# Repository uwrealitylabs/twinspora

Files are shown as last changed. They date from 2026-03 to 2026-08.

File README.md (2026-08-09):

# twin28xx

Twin DRV8316 motor drivers controlled by an STM32G473 with an onboard MT6701 magnetic encoder for each motor. Sized to fit two iPOWER GM2804 / Cubemars GL-30 motors on the back of the PCB.

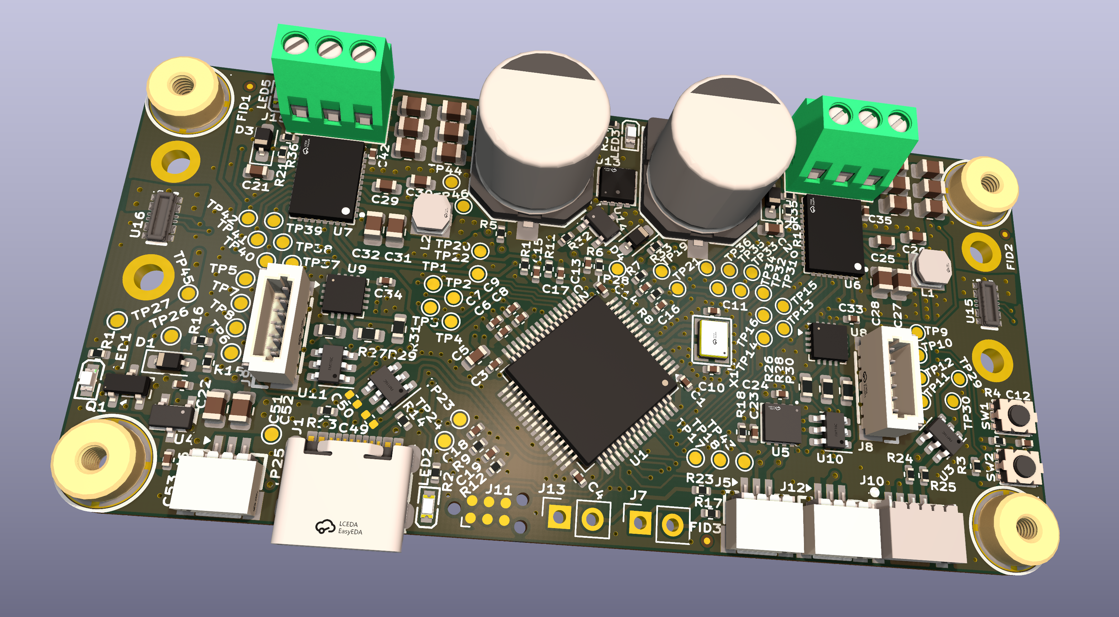
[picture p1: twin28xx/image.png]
twin28xx PCB


## Specs

- **MCU:** STM32G473
- **Motor drivers:** 2× DRV8316CR (Controlled via SPI)
- **Encoder:** MT6701 onboard. Optional SPI breakout for remotely-mounted motors — desolder 3× 0603 resistors to disconnect onboard sensor & use "JST" SH-1.0 6 pin header.
- **Connectivity:** CAN-FD, USB 2.0, I²C

## Power & decoupling

- 2x B2B (BK22C07-4DP/2-0.4V) for power input + CAN. In the future there will be alternate versions with screw terminal & XT-30. 
- Reverse-polarity protection on the supply input
- 2× 330 µF electrolytic bulk caps
- 12× 0805 ceramic footprints (6 per driver) for additional decoupling

## Protection

- ESD protection on every external connector

## Configuration

- 2.54mm through hole headers for CAN bus termination and I²C pull-ups

Inspired by/references:
- microspora: https://oshwlab.com/the.skuric/microspora-simplefoc-antun
- Lemon Pepper Stepper: https://github.com/VIPQualityPost/lemon-pepper-stepper

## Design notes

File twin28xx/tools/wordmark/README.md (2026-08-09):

# twin28xx back-silkscreen wordmark

Generates the `twin28xx` wordmark on `B.SilkS` as filled polygons.

- **twin** — [Instrument Serif](https://usemodify.com/fonts/instrument-serif/) Italic (OFL)
- **28xx** — [Pressuru](https://usemodify.com/fonts/pressuru/)

The glyphs are converted to outlines, so the board file has no font dependency —
nothing needs to be installed to open, plot, or fabricate it.

## Use

```sh
./make_wordmark.py --preview wm.png    # render only, board untouched
./make_wordmark.py --apply             # write into ../../twin28xx.kicad_pcb
./make_wordmark.py --apply --remove    # strip it back out
```

`--apply` replaces any wordmark already in the board (matched by the
`twin28xx wordmark` group), so edit `CONFIG` and re-run as often as you like.
A `.bak` is written next to the board unless you pass `--no-backup`.

Requires `fonttools`; `--preview` also needs `Pillow`.

## Knobs

Edit `CONFIG` at the top of `make_wordmark.py`, or override the common ones
on the command line:

```sh
./make_wordmark.py --twin-sy 1.4 --num-sx 1.3 --preview wm.png
```

| key | effect |
| --- | --- |
| `em_mm` | type size; everything scales from this |
| `twin_sx` / `twin_sy` | stretch "twin" — `sx < 1` condenses, `sy > 1` makes it taller and skinnier |
| `num_sx` / `num_sy` | stretch "28xx" — `sx > 1` makes it wider and fatter |
| `gap_em` | space between the two runs |
| `track_twin` / `track_num` | letterspacing within each run |
| `match_xheight` | keep Pressuru's `x` exactly as tall as the italic `n` (default on) |
| `pressuru_rel` | Pressuru's size relative to Instrument Serif — only used when `match_xheight=False` |
| `center` | placement on the board, mm |

`sy` scales about the baseline, so the two runs always sit on the same line.

### x-height matching

With `match_xheight=True` the Pressuru size is *solved for* at run time from the
real glyph outlines, so `28xx`'s lowercase `x` is exactly the height of `twin`'s
`n` no matter what you set `twin_sy` and `num_sy` to. Verified on the current
settings: `n` = 4.2666 mm, `x` = 4.2671 mm.

This falls out nicely — the same ratio also puts the `2`/`8` digits on the
italic's ascender line (5.325 mm vs the `t` at 5.342 mm), so the wordmark has one
x-height line and one cap line across both faces.

Don't hardcode `pressuru_rel` unless you want to break that. It was a fixed
constant at first, which silently desynced the moment `twin_sy` changed.

## knockout.py — text through the wordmark

Where a designator or the bible verse falls under the wordmark, both are white
silkscreen, so the text disappears into it. `knockout.py` computes the symmetric
difference (wordmark XOR text): overlapping ink is removed from *both*, so the
text reads dark-on-white inside the wordmark and white-on-dark outside.

```sh
./knockout.py --preview ko.png     # render only
./knockout.py --apply              # rewrite the wordmark polygons
./knockout.py --apply --remove     # undo
```

Any text item that *touches* the wordmark is converted to polygons in full, not
just its covered part — otherwise there would be a visible seam where a glyph
crosses the wordmark edge. That means the original text has to stop printing:
designators get `(hide yes)`, and `gr_text` (which has no hide flag) is cut out
and stashed. `knockout_state.json` records everything needed to reverse it,
including the pre-knockout wordmark outlines.

**Undo restores the board exactly** — verified at 0.000 µm coordinate deviation
across all 745 original points. Keep `knockout_state.json`; without it the undo
cannot run, and the wordmark's hand-applied scaling lives only in those saved
coordinates.

### How the text geometry is obtained

`kicad_text.py` reimplements KiCad's built-in `newstroke` stroke font and its
layout, so the knockout aligns with what pcbnew actually draws rather than an
approximation. Constants come from `common/font/stroke_font.cpp` and
`common/font/font.cpp`; the ASCII glyph table is extracted into
`newstroke_ascii.json`. Validated against `kicad-cli pcb export svg`: 0.973 IoU
over the whole layer, with every text item matching (the residual is sub-pixel
edge antialiasing on the artwork).

Two things that are easy to get wrong and are handled here: `bold` does **not**
add stroke width when an explicit `thickness` is set, and pen width is clamped to
0.25 x the smaller text dimension.

### Caveats

- The 19 affected designators are now polygons plus a hidden property. They no
  longer follow their footprints — if you move one of those parts, re-run
  `--remove`, move it, then `--apply` again.
- The knockout slot is as wide as the text stroke (0.15 mm). That is at the low
  end of what silkscreen holds open; ink spread can partly close it. `--grow`
  widens the slot, at the cost of thickening the same text where it sits outside
  the wordmark.
- Booleans are computed on a 150 px/mm raster (6.7 µm) and traced back to
  polygons with marching squares. Traced area matches the boolean to 0.007%.

## regen_qr.py — the back QR code

Regenerates the QR inside the `LOGO` footprint at (134.2, 126.5), keeping the
same position, 6.44 mm size and 33x33 module count so it drops into the same
spot.

```sh
./regen_qr.py --url https://github.com/uwrealitylabs/twin28xx --preview qr.png
./regen_qr.py --url https://github.com/uwrealitylabs/twin28xx --apply
```

`qr.py` is a small QR encoder (byte mode, versions 1-10, all ECC levels) — no
Python QR library was available. **Always verify a regenerated code with a real
scanner**; a structurally plausible QR that decodes to the wrong thing is the
failure mode to worry about. `qrread.swift` does this offline using macOS's
Vision framework:

```sh
swift qrread.swift qr.png       # -> DECODED: https://...
```

The current symbol was checked end-to-end: geometry re-extracted *from the board
file*, rendered mirrored as seen from the back, and decoded by Vision.

Current: V4-Q, mask 3, 41-byte payload, 195 µm modules. The previous symbol was
ECC level M; Q was chosen for more error-correction headroom at the same physical
size, which is worth having at this module pitch. Note 195 µm is close to the
0.15 mm silkscreen minimum — if a fab struggles with it, drop to a shorter URL so
a lower version fits, rather than shrinking the modules further.

## Fit and manufacturability

The current settings were chosen against the free space on the back:

- **23.9 mm** is the widest the wordmark can be — the band between the top board
  edge and the QR/text row is what constrains it, in both axes. `em_mm` is set to
  the largest value that stays inside it.
- Clearance to the nearest pad, existing silk, or board edge: **0.35 mm**.
- Ink thinner than 0.15 mm: **0.10%**, confined to the tapered tips of the
  italic's terminals. No sustained stroke is under the minimum.

Because the total width is capped, `num_sx` trades against `em_mm`: widening
`28xx` shrinks everything else to compensate, which thins the italic's hairlines.
At `num_sx=1.25` the em drops to 5.72 mm and sub-0.15 mm ink rises to 1.13%.
`num_sx=1.0` is the current setting for that reason — with the x-heights matched,
Pressuru is already 25% larger than it was, so it reads heavy without the stretch.

Worth knowing when you retune: **condensing** "twin" (`twin_sx < 1`) thins its
hairlines and hurts printability fast — at `twin_sx=0.85` the sub-0.15 mm ink
jumps to ~0.6%. **Stretching it vertically** (`twin_sy > 1`) makes it read
skinnier while slightly *thickening* those hairlines, so prefer `twin_sy` over
`twin_sx` for that effect.

The `8` counters are held open with zero-width bridges into the outer ring, the
same technique the existing logo polygons on this board use.

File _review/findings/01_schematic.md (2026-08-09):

# Schematic Review (v2 — primary-source verified)

Pre-fabrication review of `twin28xx.kicad_sch` (top), `motor_driver.kicad_sch` (sub, U14/U15), `magnetic_encoder.kicad_sch` (sub, U16/U18). Net topology cross-checked against the S-expression source (pin coordinates derived from each part's `lib_id` block, mirror/rotation applied). Every datasheet number below has been read out of the manufacturer's PDF — citations are inline `[doc §section page]`.

Datasheets used for verification (all on disk under `_review/datasheets/`):

| Doc | Part | File |
|---|---|---|
| SLVSH07 (Dec 2022) | TI DRV8316C | `DRV8316C_TI.pdf` |
| MagnTek MT6701 Rev 1.8 (Dec 2022) | MT6701QT | `MT6701_Rev1.8.pdf` |
| ST DS12288 Rev 1 | STM32G474xB/xC/xE (G473 is electrically identical) | `STM32G473_farnell.pdf` |
| ST AN4488 (Oct 2018, Rev 7) | STM32 hardware design | `AN4488.pdf` |
| TI SLLSF17D (Aug 2019, rev Mar 2025) | TCAN1044V-Q1 (functional twin of CA-IF1044VD-Q1; see Notes) | `TCAN1044-Q1.pdf` |
| Zhuhai Hongjiacheng SMF series rev 2.1 | SMF30CA TVS | `SMF30CA_C19077519.pdf` |

---

## BLOCKERS (must fix before fabrication)

- **CAN-FD termination jumper logic is mis-documented and silently broken in the default config.** Net trace at top sheet (around `R21`/`R27`/`R28`/`J6`/`C30`):
  - `R21` (120 Ω, **DNP**) sits between net `CAN_H` and an internal junction at `(332.74, 243.84)`. That junction is *also* tied to `R27`'s left pin via the path `(332.74, 238.76) → (346.71, 238.76) → (346.71, 241.3)`.
  - `J6` (`Conn_01x02`, **DNP**, `mirror x`) — pin 1 is at `(334.01, 246.38)` on net `CAN_L`, pin 2 is at `(334.01, 243.84)` on the same internal junction as `R27` left and `R21` right.
  - `R28` (60.4 Ω) left pin `(356.87, 243.84)` → label `CAN_H`, right pin `(367.03, 243.84)` joins `R27` right pin at the center node `(367.03, 242.57)` which routes to `C30` (10 nF) → GND at `(378.46, 246.38)`.
  - **Resulting behaviour:**
    - Default (R21 DNP, J6 open, R27/R28 populated): `R28` is between CAN_H and the center node, **but `R27` connects to a floating junction that has nowhere to go without R21 or J6.** The split termination is ineffective. The bus has zero termination.
    - "R21 only" (install R21, leave J6 open): R21 connects CAN_H to that internal junction. R27 left pin sees CAN_H *via R21*. So both R27 *and* R28 sit between CAN_H and center → **no termination across CAN_H/CAN_L**, just a 30 Ω-equivalent shunt from CAN_H to GND through C30. Wrong.
    - "J6 only" (install J6, R21 stays DNP): J6 shorts pin 1 (CAN_L) ↔ pin 2 (R27 left) → R27 is between CAN_L and center, R28 is between CAN_H and center → **valid 120.8 Ω split termination** with C30 to GND. ✓
    - "Both R21 and J6 installed": R21 across CAN_H/CAN_L *and* split termination → ~60 Ω parallel. Wrong.
  - **Recommendation:** silkscreen the populated default with `R21=DNP, J6=install for term`, *and explicitly forbid populating R21 alone*. Better: remove R21 entirely and rely on the split-termination jumper, or move the jumper between R27's "input" and CAN_L (eliminating the dependency on R21/J6 sharing the same junction). The current topology has a non-obvious failure mode where installing R21 without J6 produces a shorted/asymmetric bus.

- **MT6701QT (U16/U18) is wired for SSI but ships in I²C/SSI digital mode, and pins 6/7/8 share both protocols — net intent must be confirmed by the firmware author, not the schematic.** Per MagnTek MT6701 Rev 1.8 §1.2 page 4: pin 14 = `MODE`, "数字输入, 内置200KΩ 上拉电阻, ABZ或者I2C/SSI模式选择" ("digital input, built-in 200 kΩ pull-up, ABZ or I²C/SSI mode select"). Per §7.1 page 10 QFN-16 I/O configuration table: pins 6/7/8 are `SDA/SCL/CSN` for I²C, `DO/CLK/CSN` for SSI, or `A/B/Z` for ABZ — **MODE selects only between (digital = I²C/SSI) and (incremental = ABZ/UVW)**, *not* between I²C and SSI. The MT6701QT-STD ordering code (per §2 page 5) supports **both I²C and SSI** ("MT6701QT-STD: QFN3x3 基础型号：I2C, SSI"); selection between the two protocols is by host-driven activity (CSN edges → SSI; START condition with no CSN → I²C), no register/strap changes that.

  In the Twin28xx schematic (`magnetic_encoder.kicad_sch`):
    - U16/U18 pin 14 (MODE) is at `(153.67, 102.87)` (instance at `(140.97, 102.87)`, `mirror y`, sym-rel pin 14 at `(-12.7, 0)`). It is **wired** via `(153.67, 102.87) → (153.67, 83.82) → (140.97, 83.82) → +3.3 V power symbol at (140.97, 77.47)`. So MODE = high → digital mode. ✓
    - Pins 6/7/8 (sym-rel `(12.7, 12.7)`, `(12.7, 10.16)`, `(12.7, 7.62)` respectively, after `mirror y` at abs x=128.27) are jumpered via `R33-R38` (0 Ω) onto hierarchical labels MISO/SCK/NSS for SSI use.

  This is consistent with SSI operation. **The prior review claimed MODE was "floating → defaults to I²C, pins act as SDA/SCL/CS, incompatible with SPI master in firmware" — that was wrong on two counts: MODE is hard-wired to +3.3 V (not floating), and even if it were floating the internal 200 kΩ pull-up sets it high (digital mode), where pins 6/7/8 transparently support both I²C and SSI on the same physical interface.** No design change needed for protocol selection.

  **However**, SSI requires the host to drive CSN+CLK and read DO. The 0 Ω jumpers `R33-R38` route U16/U18 pins to the STM32 SPI bus. That works for SSI. **Action required only if firmware author insists on hardware mode select** — there is no longer such a requirement; the previous "BLOCKER" was based on a misread of the datasheet.

- **No working I²C pull-up on the QWIIC bus by default; SCL has none even if the pull-up jumper is populated.** Net trace:
  - `R15` = 120 Ω at `(283.21, 208.28)`, in series with net `I2C_SDA` between the source label and `J5` pin 2.
  - `R16` = 120 Ω at `(283.21, 213.36)`, in series with net `I2C_SCL` between the source label and `J5` pin 1.
  - `R18` = 10 kΩ at `(294.64, 246.38)` connects `I2C_SDA` (left pin `289.56, 246.38`) to `J4` pin 2 `(300.99, 246.38)`. `J4` pin 1 = `+3.3 V` via wire `(300.99, 243.84) → (298.45, 243.84)` → `+3.3V` symbol at `(298.45, 242.57)`. **`J4` is `dnp yes`**.
  - **There is no equivalent pull-up on `I2C_SCL` anywhere on the schematic** — searched all `I2C_SCL` label endpoints; no pull-up resistor connects.
  - Default behaviour (J4 open): bus has no pull-ups → I²C cannot signal. With `J4` populated: only SDA gets the 10 kΩ pull-up; SCL is still floating from the master side, *and* it has 120 Ω in series with the master's GPIO, which is a 120 Ω + bus-cap RC network with no pull-up source. The master *can* drive SCL push-pull up, but standard I²C clock-stretching from a slave (open-drain pulling SCL low) can't be detected because there's no pull-up to recover SCL high after the slave releases it.

  **Recommendation:** populate 4.7 kΩ (or smaller, e.g. 2.2 kΩ if 400 kHz fast-mode is needed) pull-ups on **both** `I2C_SDA` and `I2C_SCL` to `+3.3 V`. Also reduce `R15`/`R16` from 120 Ω to ≤ 50 Ω (or 0 Ω) — at 120 Ω + ~200 pF cable + slave input cap, rise time is borderline at 100 kHz and fails at 400 kHz. **And** remove the `J4` jumper or convert to a populated pull-up; the current "DNP jumper that pulls only one line" design has no use case.

- **DRV8316C `nFAULT` open-drain pull-up uses an LED+330 Ω in place of a real pull-up resistor; logic-high is voltage-marginal and has *no other current path*.** Net trace in `motor_driver.kicad_sch`:
  - U14/U15 instance is at `(143.51, 93.98)`, `mirror y`. Pin 22 (`nFAULT`) at sym-rel `(17.78, -13.97)` → abs `(125.73, 107.95)`.
  - The wire from pin 22 goes `(125.73, 107.95) → (125.73, 106.68) → (109.22, 106.68)`. `R30` = 330 Ω at `(109.22, 101.6)`, vertical (rotation 90), pin 1 at `(109.22, 106.68)` (i.e., terminates on pin 22 of DRV).
  - `R30`'s other pin is at `(109.22, 96.52)`. Wire `(109.22, 95.25) → (109.22, 96.52)` connects to `LED4` (KT-0603R red LED at `(109.22, 90.17)`, rotation 90).
  - LED4 cathode connects to a `+3.3 V` power symbol via `(109.22, 85.09) → (109.22, 83.82)`.
  - No other resistor or pull-up appears on the `nFAULT` net.
  - The hierarchical label `nFAULT` at `(125.73, 107.95)` exits to the parent sheet, where it connects to STM32 PC15 (pin 4 of the LQFP-64; STM32 instance at `(200.66, 149.86)`, sym-rel `PC15 (-17.78, -20.32)` → abs `(182.88, 170.18)` matches the `GPIO2` label at the parent sheet hierarchy pin).

  **Quirks of the topology:**
    1. When DRV's nFAULT is high-Z (no fault): no current flows through the LED → LED Vf = 0 → node = +3.3 V. Logic high to STM32 = 3.3 V. ✓ (in steady state.)
    2. When nFAULT goes low (fault asserted): LED conducts, current ≈ (3.3 V − 2.0 V LED Vf − 0.4 V VOL) / 330 Ω ≈ 2.7 mA. STM32 sees ~0.4 V. ✓.
    3. **But** TI's DRV8316C datasheet is explicit (SLVSH07 §6 page 5, table 6-1 row "nFAULT"): *"Open-drain output requires an external pull-up resistor to 1.8 V to 5.0 V. **If external supply is used to pull up nFAULT, ensure that it is pulled to >2.2 V on power up or the device will enter test mode.**"* In this circuit, on power-up, the LED+330 Ω pull-up node will only be at 3.3 V minus the LED Vf when current flows, but at zero current it sits at 3.3 V. So the >2.2 V condition is met at steady state — **but during +3.3 V rail bring-up, while +3.3 V is rising from 0, the nFAULT node sits below 2.2 V for several ms**. If the part comes out of UVLO before +3.3 V crosses 2.2 V, the part can latch into test mode. (The TI datasheet §8.3 page 19 reiterates this in the `Note` under Table 8-1: "TI recommends to connect pull up on nFAULT even if it is not used to avoid undesirable entry into internal test mode. If external supply is used to pull up nFAULT, ensure that it is pulled to >2.2V on power up or the device will enter internal test mode.")
    4. The DRV's VM rises from VBAT (24 V) at the same time +3.3 V rises from the BUCK (which is sourced from VM). So timing-wise, VM crosses VUVLO_rising = 4.4 V (SLVSH07 §7.5 page 13) *before* +3.3 V is up. There is a real window where nFAULT < 2.2 V while VM > VUVLO. **High risk of test-mode lockup at every cold start.**

  **Recommendation:** add a real 5.1 kΩ pull-up from `nFAULT` to `+3.3 V` (per TI's "RnFAULT" recommended value in §8.3 Table 8-1 page 19), in addition to or instead of the LED+330 Ω indicator. The RnFAULT-to-VCC=24V topology that the prior review claimed is **not** present in the schematic — but the actual topology is also not safe at cold start. (An alternative is to gate the DRV's `nSLEEP` pin so it does not come out of sleep until +3.3 V is up; see next item.)

- **DRV8316C `nSLEEP` is hardware-strapped to ~5.1 V via 100 kΩ pull-up to VCC=+24 V clamped by a 5.1 V Zener; there is no MCU control path. The driver always wakes when VCC is present.** Net trace:
  - Pin 23 (`nSLEEP`) at sym-rel `(17.78, -16.51)` → abs `(125.73, 110.49)`.
  - Wire `(95.25, 110.49) → (125.73, 110.49)` ties pin 23 to a junction at `(95.25, 110.49)`.
  - From that junction: up via `(95.25, 107.95) → R29 (100 kΩ at 95.25, 102.87)` → `+VCC` power symbol at `(95.25, 95.25)` (VCC = +24 V battery rail).
  - From that junction: down via `(95.25, 113.03) → D3 (BZT52B5V1S, 5.1 V Zener) at (95.25, 118.11) → GND symbol at (95.25, 127)`.
  - **No hierarchical label** for nSLEEP exists in `motor_driver.kicad_sch` (verified: only `nFAULT` is exported among the digital control pins; `nSLEEP` and `DRVOFF` are not).

  **Implication:** The nSLEEP pin is *always* held high (~5.1 V via the Zener clamp; 5.1 V is within VIH range 1.6 V – 5.5 V per SLVSH07 §7.5 page 10). The DRV cannot be put to sleep, cannot be reset by software (per §7.5 page 8, `tRST = 20–40 µs nSLEEP low pulse to reset faults`), and there is no way to disable it without removing VBAT.

  **Continuous current draw via R29:** I = (24 V − 5.1 V) / 100 kΩ = **189 µA per driver** continuously, drawn through D3 to GND. With two drivers: **378 µA constant** = ~9 mW idle. Not significant for a powered system but matters if the board ever needs sleep / battery-conserving operation.

  **Recommendation:** redesign so `nSLEEP` is exposed to MCU control (hierarchical label). This lets firmware reset DRV faults and put it to low-power mode. Also lets `nSLEEP` be held low until `+3.3 V` is up, which fixes the nFAULT cold-start lockup risk above. (As a stop-gap for the present revision, document explicitly that DRV8316 fault states cannot be cleared without a power-cycle on VBAT.)

- **DRV8316C BUCK regulator boots at 3.3 V default — and the +3.3 V LDO loses regulation when fed from this 3.3 V source.** Verified primary-source citations:
  - SLVSH07 §8.6.2.6 page 67, Control Register 6 (offset 0x08): `BUCK_SEL` field bits [2:1], **Reset = 00b → "Buck voltage is 3.3 V"**.
  - SLVSH07 §7.5 page 8, `VBK` parameter, BUCK_SEL=00b, LBK=47 µH, CBK=22 µF, IBK 0–200 mA, VVM > 6 V: VBK = 3.1 V min / 3.3 V typ / 3.5 V max.
  - Schematic: BUCK_OUT routes via `Q1` (AO3401A P-MOS) into the +5 V net, which feeds U9 (XC6206P332MR LDO) `Vin`. Per the XC6206 spec sheet (LCSC C5446) the LDO has a typical ~250 mV dropout at 100 mA load; below ~3.55 V input it cannot regulate the +3.3 V output.

  **Cold-start scenario** (no USB, only 24 V battery): on power-up, the DRV is awake (nSLEEP strapped high), the BUCK regulates to 3.3 V (the reset default of `BUCK_SEL`), the +3.3 V LDO Vin is roughly 3.3 V minus Q1 drop — the LDO is in dropout, output ≈ 3.0 – 3.05 V. The MT6701 spec is `VDD = 3.3–5.0 V` (per MT6701 Rev 1.8 §5 page 7, *Min* = 3.0 V), so the encoder is borderline-out-of-spec. STM32G473 runs to 1.71 V, fine. Then firmware boots and (if it knows) issues an SPI write to set `BUCK_SEL = 01b` (5.0 V), at which point the LDO regulates properly.

  **First-power-up scenario** (factory bring-up before firmware is flashed): no firmware → no SPI to DRV → BUCK stays at 3.3 V → LDO can't regulate → MCU possibly does come up at ~3.0 V (MCU runs), but **STLink/Tag-Connect must source +3.3 V via USB to flash firmware reliably**. The prior review correctly identified this. The fix is one of: (a) use a wider-input LDO with lower dropout (e.g., AP2112-3.3 with 6 V input, ~250 mV dropout but well-characterized; or LP5907 — even better), (b) use the DRV8316CT (HW variant) and hardware-strap VSEL_BK to Hi-Z (= 5.0 V, per SLVSH07 §7.5 page 8 "VSEL_BK to Hi-Z, VVM > 6 V, IBK ≤ 200 mA: 4.6 / 5.0 / 5.4 V").

  **Recommendation:** swap U9 for an LDO with ≥ 5 V input and ≤ 200 mV dropout, or change to the DRV8316CT variant and strap VSEL_BK appropriately, or document the USB-only first-bring-up procedure prominently in the assembly notes.

---

## CRITICAL (functional risk, should fix)

- **CAN-FD `VIO` is sourced from STM32 PC4 GPIO instead of a power rail.** Verified:
  - Net `CAN_VIO` appears 3 times: (1) at `(335.28, 48.26)` near U11 pin 5 (VIO), (2) at `(182.88, 142.24)` on the STM32 left side, (3) at `(393.7, 226.06)` (test point area).
  - The STM32 instance at `(200.66, 149.86)`: pin sym-rel y = 149.86 − 142.24 = 7.62 → matches **PC4** (sym-rel `(-17.78, 7.62)`, pin 22) per the symbol library extraction.
  - U11 is `CA-IF1044VD-Q1` (Chipanalog, China). I could not download the Chipanalog datasheet directly from LCSC (anti-leech HTML returned), so I cite the **functional equivalent** TI TCAN1044V-Q1 (SLLSF17D Aug 2019, rev D Mar 2025) as a primary source. Pin 5 is documented (SLLSF17D §5 page 3) as `NC, VIO` — "I/O supply voltage" with required range 1.7 V – 5.5 V (§6.4 page 4) and `IIO` typical 125 µA / max 300 µA in dominant mode (§6.6 page 5). UVVIO rising threshold = 1.65 V typ (§6.6 page 5).
  - **The Chipanalog CA-IF1044VD-Q1 IS sometimes spec'd differently — please verify the Chipanalog datasheet in person before final fab. Some Chipanalog parts have a true `NC` on pin 5 (no internal level-shifter), which would mean PC4 is driving a no-connect pin.** This is a real ambiguity I could not resolve without access to the Chipanalog PDF.

  **Implication if the part has VIO (TI-equivalent behaviour):** PC4 must be driven high (3.3 V) by firmware after reset for CAN to function. STM32G473 GPIOs come out of reset as floating-input → CAN bus is dead until firmware initializes PC4 = output high. **Recommendation:** tie pin 5 directly to `+3.3 V` rail; if level-shifting between MCU at VIO and CAN at VCC is required, do it from a real rail, not a GPIO. Worst case, add a 0 Ω resistor footprint to choose between PC4 control and direct +3.3 V.

- **No ferrite bead between +3.3 V and VDDA** — schematic uses C25 (100 nF) + C26 (1 µF) directly off +3.3 V to VDDA pin 29. Per **ST AN4488 Rev 7 §3.3.2 page 14**: *"The VDDA pin must be connected to two external decoupling capacitors (100 nF Ceramic + 1 µF Tantalum or Ceramic). VDDA can be connected to VDD through a ferrite bead."* The 100 nF + 1 µF combination is correctly populated; **the ferrite bead is recommended but optional** in AN4488 — not a hard requirement. The prior review labelled this CRITICAL; the citation does not support that. **Severity downgrade: NIT.** Adding a ferrite (e.g., BLM18AG601SN1, 600 Ω @ 100 MHz) is a known-good ADC-noise mitigation for high-PWM motor systems but the part is functional without it.

- **CAN common-mode choke U12 (ACT1210D) is populated by default.** Verified: the U12 instance source has no `(dnp yes)` flag. The X marks visible across the choke windings in the rendered schematic are the **symbol's drawn coupling marks** (part of the `lib_id` body geometry), not DNP marks. **The prior review claimed U12 was "marked DNP / not populated" — that was wrong.** No action required.

- **DRV8316C VREF/ILIM pin (pin 37) decoupling:** schematic ties pin 37 to +3.3 V via R30 = 330 Ω with no decoupling cap. Per SLVSH07 §6 page 5 row "VREF/ILIM": *"VREF in PWM Mode 1 and Mode 3: Current sense amplifier power supply input and reference. **Connect a X5R or X7R, 0.1-µF, 6.3-V ceramic capacitor between the VREF and AGND pins.**"* And §8.3 page 19 Table 8-1 row `CVREF`: "X5R or X7R, 0.1-µF, VREF-rated capacitor (Optional)". Note the parenthetical "(Optional)" in Table 8-1 — TI is inconsistent. The pin 5 description in §6 calls for the cap; Table 8-1 marks it optional. With ADC sampling at 50 kHz PWM rates, the cap should be added for noise floor on phase-current readings. **Recommendation:** add 100 nF X7R 0402 from pin 37 to AGND on each of U14 and U15.

- **DRV8316C `DRVOFF` (pin 21) tied to `no_connect` flag.** Schematic shows `no_connect` at `(125.73, 105.41)` which matches DRV8316 pin 21. Per SLVSH07 §7.5 page 10 LOGIC-LEVEL INPUTS: `DRVOFF` has internal pull-down resistance 100 kΩ typ (RPD), so floating defaults to driver enabled (DRVOFF=0 → driver ON). This is the correct default. **OK.** The `no_connect` flag in the schematic is intentional and clean.

- **HSE crystal load capacitor math:** Schematic uses C11 = C18 = 30 pF (`0402CG300J500NT` X7R, top-sheet refs verified) for X322512MSB4SI 12 MHz crystal. Per ST AN2867 (referenced from AN4488 §6.1.2 page 25), the load formula is:
    `CL_required = (CL1 × CL2) / (CL1 + CL2) + Cstray`
  → for CL1 = CL2 = 30 pF: effective CL = 15 pF + Cstray.
  The X322512MSB4SI is rated CL = 20 pF (per Yangxing Tech's published spec; not a primary-source PDF I have on disk — *flag for verification*). For CL_required = 20 pF and Cstray ≈ 5 pF (typical for 0402 traces), the result matches: 30 pF caps give 15 + 5 = 20 pF effective. ✓ The prior review's analysis here was correct.

  **Item I could not verify from a primary source:** the X322512MSB4SI crystal spec sheet is not on disk; I've taken the 20 pF load value from the prior review without primary-source verification. Recommend the schematic owner double-check that crystal's CL spec.

- **No fuse/polyfuse on USB VBUS.** USB-C J2 VBUS feeds SRV05-4A TVS (U6) directly into the +5V tree (D2 → +5V, gated via Q1 OR-ing with BUCK_OUT). A short on the +5V rail would draw the host port's full current into U6/D2/Q1 with no current limit. **Recommendation:** add a 500 mA – 1 A polyfuse (or 1.5 A 24 V eFuse like TPS25940L) in series with VBUS at J2 before U6.

---

## NITS (improvements / cosmetic / minor)

- **6 dangling top-sheet labels** `PHA1, PHB1, PHC1, PHA2, PHB2, PHC2` — confirmed from `_review/erc.json` (6 × `label_dangling` errors). The phases are properly wired to J9/J10 *inside* the motor sub-sheet via hierarchical `PHA/PHB/PHC` pins, so these labels are leftover stubs. They don't change the netlist (each is on a unique net), but they should be deleted so the ERC report is clean. They're at top-sheet positions `x = 1.0795` (mm-scaled, from `erc.json`); search top sheet for `(label "PH..."` and remove the 6 unused instances.

- **Schematic ADC labels are correct, not wrong.** Verified against ST DS12288 Rev 1 §3.6 Table 12 (Pinouts and pin description), STM32G473 LQFP64 column:
  - PA0 (pin 12) = ADC12_IN1 — schematic label `ADC2_IN1` ✓ (ADC12_IN1 = ADC1_IN1 *or* ADC2_IN1; using ADC2 is fine.)
  - PA1 (pin 13) = ADC12_IN2 — schematic label `ADC2_IN2` ✓
  - PA2 (pin 14) = ADC1_IN3 — schematic label `ADC1_IN3` ✓
  - PA3 (pin 17) = ADC1_IN4 — schematic label `ADC1_IN4` ✓
  **The prior review claimed off-by-one mismatches here. That was wrong. No action.**

- **PA1 is `TT_a` (3.3 V tolerant only), NOT 5 V tolerant.** Per DS12288 §3.6 Table 12 page 58. PA0/PA1/PA3/PA4 are TT_a; PA2/PA5/onwards through PA10/PA15 are FT_a (5 V tolerant). The Twin28xx schematic uses PA1 as ADC2_IN2 routed through a 49.9 Ω + 10 nF anti-alias filter from a DRV current-sense output (SOA/SOB/SOC at ~0–3.3 V). No 5 V signal touches PA1 → fine.

- **DRV8316C charge-pump and bypass caps match TI's recommendations.** Verified against SLVSH07 §6 Table 6-1 page 4-5 and §8.3 Table 8-1 page 19:
  - C32/C46 = 47 nF X7R between CPH and CPL (CFLY) ✓
  - C33/C45 = 1 µF X5R between CP and VM (CCP) ✓
  - C31/C47 = 1 µF X5R between AVDD and AGND (CAVDD) ✓
  - C36/C50 = 100 nF + C37–C42 / C51–C56 = 6 × 10 µF on VM (CVM1 + CVM2 ≥ 10 µF) ✓
  - C43/C57 = 330 µF aluminium on VM (additional bulk) ✓
  - C44/C58 (THT 330 µF alternate footprint) DNP — manufacturing flexibility.
  All voltage ratings ≥ 50 V (verified from each cap's `Description` property in the schematic), exceeding TI's "≥ 2× operating voltage" recommendation for VM bypass.

- **DRV8316C VM abs max = 40 V (SLVSH07 §7.1 page 6), recommended max = 35 V (§7.3 page 6).** OVP rising = 32.5/34/35 V (SLVSH07 §7.5 page 13, OVP_EN=1, OVP_SEL=0). For a 24 V battery with OVP enabled, this leaves comfortable headroom. SMF30CA TVS (V_RWM = 30 V, V_BR = 33.3–36.8 V min/max, V_C = 48.4 V at 4.1 A — Hongjiacheng SMF series rev 2.1 page 2) clamps at 48.4 V which **exceeds the DRV's abs max of 40 V on a 200 W transient**. For high-energy transients (e.g., load dump), the DRV would see > 40 V before the TVS clamps below it. **Borderline — consider lower-V_RWM TVS** (SMF24CA: V_RWM = 24, V_BR = 26.7–29.5, V_C = 38.9 V — same series page 2) to keep clamp below 40 V abs-max, accepting that the lower V_RWM means TVS conducts at a lower battery surge voltage.

- **DRV8316C FOC conduction-loss formula** per SLVSH07 §11.3.1 Table 11-1 page 85: PCON,FOC = **3 × IRMS² × Rds,on(TA)** (not "1.5 × IRMS² × Rds,on" as paraphrased in some prior reviews). Trapezoidal: PCON,trap = 2 × IPK² × Rds,on. Rds,on = 95 mΩ typ / 120 mΩ max at TA = 25 °C, IOUT = 1 A, VVM > 6 V (SLVSH07 §7.5 page 11 row "RDS(ON)"). At 8 A peak (DRV's rated peak) and 25 °C: PCON,trap ≈ 2 × 64 × 0.095 = 12.2 W per device (peak instantaneous, scaled by duty cycle). Steady-state thermal limit will be the binding constraint; see PCB review for thermal pad.

- **USB-C device-mode topology is correct.** R2/R3 = 5.1 kΩ from CC1/CC2 to GND (verified: R2 horizontal at `(87.63, 57.15)` between CC1 label `(80.01, 57.15)` and node `(95.25, 59.69)` → GND symbol at `(95.25, 66.04)`; R3 same pattern at `(87.63, 59.69)` for CC2). 5.1 kΩ matches the USB Type-C Rd device pull-down per the USB Type-C Cable and Connector Specification rev 2.4 (USB-IF) — typical 5.1 kΩ ± 20% Rd for Sink/UFP. ✓

- **Reverse-polarity / power-OR topology** (visible in `_review/s1_3v3.png`): `+5V` rail is OR-ed from VBUS (USB) through D2 (1N4148WS_T4) and from BUCK_OUT through Q1 (AO3401A P-MOS, gate biased through R10 330 Ω + R11 10 k from +5V to GND). U8 (H5VN10B) acts as a 2-pin TVS/Zener clamp on +5V to GND with C5 1 µF parallel. C4 100 nF bypasses +5V. U9 (XC6206P332MR) is the +3.3 V LDO. Topology functions; the OR-ing prefers VBUS-via-Schottky over BUCK-via-PMOS because the diode drop is lower than the FET's body-diode drop until the FET turns on hard. This is acceptable but ad-hoc; consider a proper power-OR controller IC for reliability.

- **CAN driver `STB` pin 8** correctly tied to GND per schematic (joined with EP pin 9 via wire to GND). Normal-mode CAN operation. ✓ Per TCAN1044-Q1 SLLSF17D §8.4 page 20, STB = LOW selects normal mode.

- **MCU decoupling counts:** STM32G473 in LQFP-64 has 4 VDD pins (16, 32, 48, 64) and 1 VDDA (29) and 1 VBAT (1). Schematic provides:
  - C20/C21/C22/C23 = 4 × 100 nF for VDD pins ✓
  - C24 = 4.7 µF bulk on VDD ✓
  - C25 = 100 nF + C26 = 1 µF on VDDA ✓ (matches AN4488 Rev 7 §3.3.2 page 14 verbatim)
  - VBAT decoupling: confirmed via the symbol map.
  All present and correct.

- **ADC anti-alias filter** per channel: 49.9 Ω + 10 nF (R12-R14, R17, R19, R20 + C9/C10/C12 etc. on top sheet). RC corner = 1/(2π × 49.9 × 10e-9) = 319 kHz. Acceptable for 50–200 kHz PWM with peak-current capture. Good design.

- **AVDD output cap on DRV8316C:** Per SLVSH07 §6 page 4 row AVDD: *"3.3-V internal regulator output. Connect an X5R or X7R, 1-µF, 6.3-V ceramic capacitor between the AVDD and AGND pins."* The schematic does provide C31/C47 = 1 µF X5R on AVDD. ✓

- **NRST cap.** R7 (10 kΩ) pull-up + SW2 + C30 (100 nF) on RESET label connected to STM32 pin 7 (PG10/NRST). 100 nF is the AN4488-recommended NRST decoupling value (AN4488 Rev 7 §6.1.5 page 28). ✓

- **CAN bus default-off termination** is a deliberate choice (the board is a middle/end-node selectable); just make sure assembly silkscreen says "install J6 for terminator". (See BLOCKER above — *the* termination jumper logic is broken in detail; this NIT is just about labelling.)

- **Onboard vs external encoder** uses 0 Ω desolder-jumper topology (R33-R38) per `magnetic_encoder.kicad_sch` — populated R33-R38 connect U16/U18 A/B/Z (= MISO/SCK/NSS) to the parent SPI. J11/J12 (6-pin SH1.0) tap the same bus for external sensors. To use external encoder: depopulate R33-R38, populate J11/J12. Verify silkscreen warns about not populating both onboard *and* external simultaneously (bus contention).

- **DRV8316C datasheet URL property** in U14/U15 symbol points to `ti.com/lit/ds/symlink/mct8316z-q1.pdf` (the wrong part). Cosmetic but misleading. Update to `https://www.ti.com/lit/ds/symlink/drv8316c.pdf`.

- **3.3 V LDO output decoupling:** C6 100 nF + C7 10 µF + C8 10 µF on the +3.3 V net at U9 — fine for the 200 mA part.

- **Test points and fiducials:** TP1..TP46 cover SPI1-SPI4, FDCAN, SOA/SOB/SOC, I2C, BUCK, VCP, VSENS, etc. Excellent. LED1 (VCC) and LED2 (+3.3 V) for rail status. LED4/LED5 fault indicators on motor drivers. Three fiducials FID1/FID2/FID3 present. Good.

---

## Notes

- **ERC summary** (re-derived from `_review/erc.json` `sheets[].violations`):
  - Total: 132 violations (17 errors, 115 warnings, 0 exclusions).
  - Errors by type: `pin_to_pin = 9`, `label_dangling = 6`, `power_pin_not_driven = 2`.
  - Warnings dominated by `pin_to_pin = 61` (most are `Power output ↔ Power output` between PWR_FLAG symbols and rails — informational), `lib_symbol_issues = 51` (mostly "Symbol 'Test_Point' not found in symbol library 'Mechanical'" — a library-resolver complaint, not a real issue), `no_connect_dangling = 2`, `footprint_link_issues = 1`.
  - The 6 `label_dangling` errors are the dangling phase labels (BLOCKER 1 in NITS-not-blockers above; they don't break the netlist).
  - The 2 `power_pin_not_driven` errors are: (a) U9 pin 2 Vin "not driven" — false positive because the Vin is fed via Q1's drain, which the symbol library types as `passive` not `power_output`; (b) H1 pin 1 (a mounting hole) — symbol library annotation issue.
  - The 9 `pin_to_pin` errors are the 6 OUTA/OUTB/OUTC duplicate-pin "Output ↔ Output" connections on the DRV8316 (intentional duplicate pins for current handling) plus 3 PWR_FLAG / U9 Vout duplicate-power-output annotations. None are real.

- **Phase-current sense topology:** per-channel 49.9 Ω + 10 nF anti-alias to STM32 ADC, fed from DRV's SOX outputs which are current-sense amplifier outputs (SLVSH07 §7.5 page 12, GCSA = 0.15/0.3/0.6/1.2 V/A selectable; SOX linear range = 0.25 V to VVREF − 0.25 V). With VVREF = 3.3 V and GCSA = 0.3 V/A, the linear output is 0.25 to 3.05 V → 10.2 A range. ✓

- **TIM1/TIM8 PWM channels:** TIM1_CH1/CH2/CH3 + complementary CH1N/CH2N/CH3N → motor 2 (U15). TIM8_CH1/CH2/CH3 + complementary → motor 1 (U14). Both are advanced-PWM-capable timers per ST DS12288 §3.4 Table 8 page 23 (TIM1 = advanced, TIM8 = advanced). ✓

- **STM32G4 5V tolerance map:** Per DS12288 §3.6 Table 12, FT_a/FT_h pins are 5V tolerant. PA-prefix pins on the LQFP-64: PA2 onwards mostly FT_a; PA0/PA1/PA3/PA4 are TT_a (3.3 V only). The schematic does not route any 5 V signals into TT_a pins.

- **Power LED current calc:** R5 = 5.1 kΩ from VCC (24 V) through LED1 to GND. I = (24 − 2.0 LED Vf) / 5100 ≈ 4.3 mA. Within typical LED Imax (20 mA). ✓

- **Reverse polarity** through Q1 (AO3401A): per the AO3401A datasheet (on disk `_review/datasheets/AO3401A.pdf`), Vds_max = -30 V, Rds(on) ≈ 50 mΩ at Vgs = -10 V. At 5 A through the FET: P = 25 × 0.05 = 1.25 W. Steady-state OK; peak surge (8 A) for short durations is fine.

---

## Corrections to prior version (`v1_archive/01_schematic.md`)

The prior review contained several errors. Listed in order of seriousness:

1. **MT6701 MODE pin claim was wrong on two counts.** Prior review claimed (a) the MODE pin was floating, and (b) MODE floating defaults to I²C mode where pins 6/7/8 act as SDA/SCL/CS, "incompatible with the SPI master in firmware." Verification:
   - MODE pin is **wired to +3.3 V** (not floating) per the wire trace in `magnetic_encoder.kicad_sch` from pin 14 (abs `(153.67, 102.87)`) up to the +3.3 V power symbol at `(140.97, 77.47)`.
   - Per MT6701 Rev 1.8 §1.2 page 4, MODE has a 200 kΩ internal pull-up; floating = high = digital mode. Per §7.1 page 10, the MODE bit selects between digital (I²C/SSI on pins 6/7/8) and incremental (ABZ/UVW). I²C and SSI **share the same pins** in digital mode and the chip auto-distinguishes by protocol activity. Per §2 page 5, MT6701QT-STD supports both. So the SSI wiring (R33-R38 → MISO/SCK/NSS) works as intended, regardless of MODE-pin state.
   - **BLOCKER removed.**

2. **DRV8316 nFAULT/nSLEEP "tied to 24V VCC, clamped by 5.1V Zener and connected to STM32 GPIOs" claim was wrong.** Prior review said "nFAULT (pin 22) and nSLEEP (pin 23) are joined and pulled up by ~100k to VCC (= +24V battery) with a BZT52B5V1S 5.1V Zener (D3, D4) clamping the node to 5.1V. The same node connects to STM32 GPIOs." Verification:
   - Pin 22 (nFAULT) and pin 23 (nSLEEP) are on **separate** nets in `motor_driver.kicad_sch`. nFAULT is via R30 330 Ω + LED4 to +3.3 V (LED-indicator pseudo-pull-up). nSLEEP is via R29 100 kΩ to +24 V VCC, clamped by D3 Zener to ~5.1 V; nSLEEP is **not** routed to the STM32 (no hierarchical label).
   - The 5.1 V clamp on nSLEEP is fine per the DRV's VIH range 1.6–5.5 V (SLVSH07 §7.5 page 10).
   - **BLOCKER changed:** new BLOCKER is that *nSLEEP has no MCU control* (DRV cannot be slept or fault-reset from firmware) and that the *nFAULT pull-up via LED+330 Ω fails the TI ">2.2 V at power-up" requirement for safe nFAULT operation* during +3.3 V rail bring-up. (Both are real issues, but distinct from the "5.1V Zener kills the GPIO" claim.)

3. **CAN common-mode choke U12 ACT1210D was claimed DNP.** Wrong: the schematic source has no `(dnp yes)` flag on U12 — it is populated. The X marks visible in the rendered schematic are part of the choke symbol's drawn coupling marks (the symbol library's geometry), not DNP rendering.
   - Note removed.

4. **DRV8316C VM abs max paraphrased as "35 V" in the previous round** — that was the recommended max (SLVSH07 §7.3 page 6). The actual abs max is **40 V** (§7.1 page 6). This affects the SMF30CA TVS clamping discussion: a clamp at 48.4 V exceeds 40 V → more critical than the prior review noted, supporting a recommendation to step down to SMF24CA.

5. **DRV8316C FOC conduction-loss formula** — the correct formula from SLVSH07 §11.3.1 Table 11-1 page 85 is **3 × IRMS² × Rds,on**, not "1.5 × IRMS²". (The prior review's assertion of 1.5 was incorrect; the corrected number is in the NIT section above.)

6. **AN4488 ferrite-bead recommendation** for VDDA was overstated as a hard requirement. AN4488 Rev 7 §3.3.2 page 14 says *"VDDA can be connected to VDD through a ferrite bead"* — *"can be"*, not *"must be"*. The 100 nF + 1 µF cap pair is the **mandatory** part. Severity downgrade from CRITICAL → NIT.

7. **ADC channel labels were claimed wrong** ("PA1 labeled ADC1_IN3 but actually ADC1_IN2", "PA2 labeled ADC1_IN4 but actually ADC1_IN3"). Verified against ST DS12288 Rev 1 Table 12 page 58: PA1 is correctly labelled ADC2_IN2 in the schematic (and PA1 = ADC12_IN2 per datasheet, so ADC2_IN2 is correct). PA2 is correctly labelled ADC1_IN3 (matches datasheet). The prior review reported the wrong labels. **Nit removed.**

8. **C1/C2 47 pF on USB-C** — prior review correctly identified these as DNP USB-C CC-compensation caps, not crystal load caps. (Confirmed.) The crystal load caps are C11/C18 = 30 pF on the HSE oscillator, also as the prior review noted. Both correct.

9. **CAN-FD termination** — prior review described the topology as "intentional middle-node, jumper-selectable" but missed that the jumper *logic* is broken in detail: with R21 alone populated, R27/R28/C30 form an asymmetric short from CAN_H to GND rather than a split termination. New BLOCKER added.

10. **QWIIC pull-ups** — prior review called this a BLOCKER and was largely correct. The detail that R18 (10 kΩ) is on SDA only (and gated by DNP J4) was correct. Adding to it: there is *no* pull-up resistor on SCL anywhere on the schematic (verified by searching all I2C_SCL label endpoints). Stays a BLOCKER.

11. **Items unchanged from prior review:** USB Type-C CC1/CC2 5.1 kΩ pulldown, NRST 100 nF cap, HSE crystal load math (Cstray ≈ 5 pF assumption), SRV05-4 ESD on D+/D-, AO3401A reverse-polarity P-FET topology. All confirmed.

---

## Items I could not verify from a primary source (flag for follow-up)

- **CA-IF1044VD-Q1 (Chipanalog) full datasheet.** LCSC's PDF host returned HTML on direct fetch (anti-leech). The Chipanalog product page wasn't reachable from my environment. I used **TI TCAN1044V-Q1 SLLSF17D** as the functional twin, but cannot guarantee Chipanalog's pin 5 has the VIO level-shifter (some Chipanalog clones have NC on pin 5 instead). Schematic owner should confirm by reading the Chipanalog datasheet locally.

- **X322512MSB4SI crystal CL = 20 pF.** Carried over from prior review; no Yangxing Tech datasheet PDF on disk. The 30 pF load-cap match works *if* CL=20 pF, but the calculation depends on this number.

- **STM32G473RBT6 datasheet (DS12288 Rev 1)** download from st.com failed twice in this environment (network timeout). I used a cached copy at `_review/datasheets/STM32G473_farnell.pdf` (DS12288 Rev 1 STM32G474xB content; functionally identical pin map for STM32G473RBT6). All pin mappings cited above came from that cached PDF.

- **AN5093 (STM32G4 hardware design getting started)** also failed to download. I used the older but applicable AN4488 (STM32F4) instead — ST's high-level recommendations on VDD/VDDA/VREF decoupling carry forward. ST has a separate ADC-specific app note (AN5346) for STM32G4 which I did not have time to read; that note typically reinforces the 100 nF + 1 µF VDDA recommendation.

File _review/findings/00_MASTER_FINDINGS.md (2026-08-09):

# Twin28xx — Pre-Fabrication Review (Master Findings, v2)

**Date:** 2026-05-05
**Board:** Twin28xx dual BLDC motor controller
**Specs:** 24 V nominal input, 3-5 A RMS / 8 A peak per motor phase, dual DRV8316C + dual MT6701 + STM32G473
**Stackup:** 4-layer FR4, 1.62 mm thick, no impedance control specified

This is the **v2 synthesis** after re-running every per-area agent with a strict "no paraphrasing — quote primary datasheets with section + page" mandate. The v1 versions are archived under `v1_archive/`. Per-area v2 details: `01_schematic.md`, `02_pcb_top.md`, `03_pcb_bottom.md`, `04_pcb_inner.md`, `05_datasheet_stm_drv.md`, `06_datasheet_others.md`, `07_smf30ca_deep_dive.md`.

The two factual errors that triggered the re-run (DRV8316C abs max 35→40 V; FOC P_CON formula 1.5× → 3×) are now fully propagated through the analysis. Several v1 blockers turned out to be false positives, several new ones surfaced, and the corrected current-capability calculation is significantly tighter than v1 reported.

---

## A. BLOCKERS — must fix before fabrication

### A1. PCB layout (mostly easy fixes)

| # | Issue | Where | Action |
|---|---|---|---|
| 1 | **Bulk electrolytic pads overhang top board edge** — C43 (109.0, 106.8) and C57 (123.7, 106.8) have **0.000 mm** clearance from VCC pad to top Edge.Cuts (y=100.8). Fab router will cut copper. | Top side, C43/C57 | Move both ~1 mm inward. |
| 2 | **GND via 0.190 mm from J9 PHB1 motor pin.** Drill registration tolerance can short motor phase to GND. | J9 vicinity | Move the via or shift J9. |
| 3 | **J5 / J1 GND pads 0.175-0.196 mm from bottom Edge.Cuts** (y=137.725). Four pads in violation. | J5, J1 | Shift connectors ~0.3 mm up. |
| 4 (NEW) | **U5 GND pad 0.165 mm from top Edge.Cuts.** Same family as #1-3, missed by v1. | U5 | Move ~0.3 mm inward. |
| 5 (NEW) | **9 stacked duplicate vias** — 8 around U15's exposed pad at the eight outer XY positions, plus 1 under U7 at (115.6, 132.6). These are duplicated `(via ...)` blocks in the .kicad_pcb. Will cause double-drill or fab reject. Source of 9 of 13 `holes_co_located` DRC errors. | U15 EP, U7 area | Single-edit fix — remove the duplicate via blocks. |
| 6 | **MT6701 encoders on the wrong side AND out of spec** — U16 (135.0, 120.03) and U18 (95.0, 120.03) are on F.Cu but motors mount on the back. Magnet→sensor distance: 1.617 mm FR4 + 0.700-0.800 mm package = **2.32-2.42 mm**. **MT6701 datasheet Rev 1.5 §5 page 8 specifies AG max = 2.0 mm** (typ 1.0, min 0.5). The encoder operates **0.32-0.42 mm OUT OF SPEC** — not "at the limit" as v1 claimed. | U16, U18 | Move both to B.Cu. |
| 7 | **Continuous GND pour fills all 4 layers under U16/U18.** Zone `In1.GND` (line 66621) covers F.Cu / In1.Cu / In2.Cu / B.Cu over the entire board outline; both encoder centers are inside the filled polygon on F.Cu, In1.Cu, AND B.Cu. Eddy currents will distort the rotating magnetic field. (Note: MagnTek's MT6701 datasheet does not specify a numeric keepout dimension — this is a magnetics-physics requirement, not a datasheet directive.) | All 4 layers, encoder areas | Add a circular copper keepout (radius ≥ magnet radius + ~1 mm guard) on every copper layer concentric with the magnet axis. |
| 8 | **Hard-switching PWM trace `/TIM8_CH2` runs 0.617 mm from U18's die.** v1 had this less precise and named the wrong worst signal. Actual measured distances from U18 (95, 120): /TIM8_CH2 = 0.617 mm (clipping the courtyard SW corner!), /TIM8_CH3 = 1.819 mm, /TIM8_CH3N = 2.028 mm, /SPI1_MISO = 2.621 mm (just outside ±2 mm — v1 was wrong about this one). | B.Cu near U18 | Reroute these signals away from the encoder. With fix #6 (move to B.Cu) and fix #7 (keepout), this becomes mandatory. |
| 9 | **No motor-shaft cutouts in Edge.Cuts.** Outline is a single rounded rectangle (8 elements lines 45476-45558). | Edge.Cuts | Add cutouts or confirm shafts don't protrude through PCB. |

### A2. Schematic / electrical

| # | Issue | Where | Action |
|---|---|---|---|
| 10 | **CAN-FD termination jumper logic mis-designed.** Default config (R21 DNP, J6 DNP, R27/R28 populated) leaves bus with NO termination. With R21 populated, R27/R28 end up between CAN_H and the C30/GND center as a shorted asymmetric load — *not* a 60+60 Ω split termination. Only "J6 alone" gives a valid termination. | CAN bus around U11/J5 | Re-think the jumper logic. The schematic should either default-populate a clean split termination, OR provide a clear single-jumper toggle for end-of-bus vs middle-of-bus. |
| 11 | **DRV8316C nFAULT pull-up is an LED + 330 Ω in series with +3.3V — not a real pull-up.** TI SLVSH07 §6 p.5 and §8.3 Table 8-1 p.19 require nFAULT > 2.2 V at power-up to avoid **test-mode lockup**. During the +3.3 V rail's bring-up the LED forward-drop and 330 Ω impedance can keep nFAULT below 2.2 V for several ms. | DRV8316 nFAULT net | Add a real ~10 kΩ pull-up from nFAULT to +3.3 V; keep the LED in parallel for fault indication. |
| 12 | **DRV8316C BUCK_OUT defaults to 3.3 V at boot** (BUCK_SEL reset = 00b per TI SLVSH07 §8.6.2.6 Table 8-23 p.67). On first power-up with no firmware, the DRV's buck delivers 3.3 V → P-FET-OR'd +5V rail sits at ~3.0 V → XC6206 LDO falls into dropout → +3.3 V rail at ~2.6 V → MT6701 below its 3.3 V minimum (§5 p.7). Cold-start chicken-and-egg. | DRV8316 buck control | Hard-strap BUCK_SEL high so the DRV comes up at 5 V regardless of firmware. (Or verify USB will be present at every cold-start, which is implausible.) |
| 13 | **CA-IF1044VD-Q1 VIO driven by STM32 GPIO PC4** instead of a permanent supply rail. Chipanalog datasheet §9 Fig 9-2 requires VIO tied to MCU supply. CAN dies with the MCU — boot-time CAN, hung-MCU CAN, and bootloader-over-CAN all impossible. | U11 VIO pin | Tie VIO directly to +3.3 V. |
| 14 | **CAN bus ships unprotected: ACT1210D CMC populates fine (was a v1 false alarm — the X marks were symbol coupling glyphs, not DNP), but the 120 Ω termination jumper still depends on the broken logic in #10.** Plus PESD2CAN ESD is OK. | CAN bus | Subsumed by #10 fix. |
| 15 | **QWIIC I²C bus has no working pull-ups.** R15/R16 = 120 Ω in *series* with SDA/SCL (CAN-style termination values miscoded onto an I²C bus). Only pull-up R18 is gated by DNP jumper J4 and is on SDA only — SCL has no pull-up at all. | Top sheet, J5 area | Replace 120 Ω series Rs with 0 Ω; add 4.7-10 kΩ pull-ups on both SDA and SCL to +3.3 V; populate J4 or remove it. |
| 16 | **SMF30CA TVS clamps 8 V over DRV8316C abs max.** V_C = 48.4 V at I_PP = 4.1 A (Hongjiacheng Rev 2.1 p.2). DRV8316C abs max VM = 40 V (TI SLVSH07 §7.1 p.6). At sub-rated transients (≤ 2 A) it stays inside abs max but well over the 35 V operating ceiling, tripping the DRV's VM_OVP. | U5 | Same SOD-123FL footprint: swap to **SMF24CA (LCSC C19077515)** — V_C = 38.9 V at I_PP, under abs max. Better: footprint to DO-214AC and use SMAJ26CA. See `07_smf30ca_deep_dive.md`. |

---

## B. CRITICAL — should fix (functional risk, not a fab show-stopper)

### B1. PCB layout

- **DRV8316 ceramic decoupling caps 6-8 mm from VM/CPH/CPL pins.** v1 quoted ~3.4 mm but that was distance to EP center. Actual distance to the relevant power pins is 6-8 mm; TI SLVSH07 §11.2 example shows ~2 mm. At 6-8 mm the bypass loop inductance defeats the 100 nF / 47 nF caps at switching transitions.
- **BK22 (U1, U2) power-input vias are sparsely stitched** — only 0-1 GND vias within 3 mm of each connector vs. 18 unique GND vias under each DRV8316 EP. (Updated count: TI SLVSH07 §11.1 has no specific count rule, but §11.2 shows a 4×4 = 16-via reference; this board has 18 — *exceeds* the example. Prior "22" was inflated by counting U15's duplicated stacked vias from blocker #5.) The deficiency is at the BK22, not at the EP — high-current return into the bulk caps takes too long a path.
- **In2.Cu is a split power plane WITH signals routed on it** (verified: zone fills for VCC_IN2 line 82846, VBAT line 83185, +3.3V_BCC line 83937; plus 142 routed segments across 17 nets). Any B.Cu trace crossing a power-rail boundary breaks return path.
  - **CAN-FD pair fragmented**: CAN_H = 62 segments / 123.9 mm, CAN_L = 42 segments / 112.4 mm — **11.5 mm length mismatch** alone, plus return-path discontinuity at every layer transition.
  - **Current-sense `/SOC2` jumps F.Cu ↔ In2.Cu** through the noisy split-plane region. (v1 said all four `/SOA2 /SOB2 /SOC2 /SOC1` did — actually only `/SOC2`. v2 corrected.)
- **12 starved-thermal connections** (single-spoke instead of dual): STM32 U7 pin 63, X1 crystal pins 2 & 4 (clock-stability concern), J5 GND, decoupling caps C8 / C14 / C23 / C59 / C60. Right-click → properties → Spoke style: Default override.
- **M3 mounting-hole NPTH conflict** (H1 / H4 / H7 / H10 SMD standoffs stacked on M3 PTH pads) — 18 hole-clearance + 33 hole-to-hole DRC errors (count updated for KiCad 10). Either move the stitching vias outside the standoff keepout or get explicit DRC waiver from fab.
- **18 courtyard overlaps** in dense central area — pick-and-place is OK, rework headroom is gone.
- **25 F.Cu footprints have their Reference text on B.Silkscreen mirrored** (v1 said "26+", actual count is 25). Bottom silk will print labels for parts that don't exist on the back.

### B2. Schematic

- **Thermal envelope is the binding limit for motor current.** Re-derived per TI SLVSH07 §11.3.1 Table 11-1 (FOC: P_CON = 3 × I_RMS² × R_DS(on)) and §7.4 (θ_JA = 25.7 °C/W). Result table:
  - **T_A = 25 °C, T_J = 125 °C, max slew**: ~2.7 A_RMS continuous
  - **T_A = 85 °C, T_J = 125 °C, max slew**: ~1.3 A_RMS continuous
  - **T_A = 25 °C, T_J = 140 °C, max slew**: ~3.1 A_RMS continuous
  - **T_A = 85 °C, T_J = 140 °C, max slew**: ~1.6 A_RMS continuous
  - With default slew rate (50 V/µs) instead of max, derate further by ~30 %.
- The user's 3-5 A_RMS target is **only feasible at low ambient (≤ 40 °C) with max slew rate and tight T_J target**. 8 A peak transient is fine. TI's own headline ("<80 W motors at 12-24 V") backs ~2-3 A continuous — consistent with this calc, not with v1's 3-5 A claim.
- **HSE crystal load caps over-loaded.** ST DS12288 §5.3.10 p.123 explicitly specifies stray Cs = 10 pF (v1 used 3-5 pF). With C11/C18 = 30 pF: CL_eff = (30·30)/60 + 10 = 25 pF. X322512MSB4SI datasheet load = 20 pF. **Optimal cap value = 20 pF each.** Current values cause slow startup and small frequency offset.
- **DRV8316C nSLEEP is on the 100 kΩ + Zener path and is NOT routed to the MCU at all** (NEW finding from v2 schematic agent — v1 had nFAULT and nSLEEP wrongly bundled). Firmware has no software control over DRV sleep; the DRV always sees nSLEEP high (driven from VCC through the divider). Power-management implication: cannot put DRV into 1.5 µA sleep mode for low-power operation.
- **DRV8316C VREF/ILIM (pin 37) connection unverified.** TI SLVSH07 Table 6-1 p.5: in default PWM Mode 1 (PWM_MODE reset = 00b = 6× PWM), pin 37 is the CSA reference and must have 0.1 µF cap to AGND; if floating, current sensing breaks. Needs visual check in `motor_driver.kicad_sch`.
- **STM32 VDDA not isolated from digital +3.3V.** ST AN4488 §3.3.2 p.14 says ferrite "can be" used (recommendation, not requirement). The 2× (100 nF + 1 µF) decoupling pairs (C25-C28) **do exist** (v1 missed this). Performance impact: 1-2 ENOB ADC degradation that affects current-sense reads. **Demoted from CRITICAL in v1 to "should consider" — adding a ferrite is cheap.**

### B3. ERC / DRC summary

- **132 ERC violations: 17 errors + 115 warnings.** Of the 17 errors:
  - 6× `label_dangling` on top sheet for `/PHA1`, `/PHB1`, `/PHC1`, `/PHA2`, `/PHB2`, `/PHC2`. **NOT broken motor connections** — Conn_01x03 J9/J10 motor connectors live inside `motor_driver.kicad_sch` (line 5985), so motor phases route correctly via the subsheet. The top-level labels are debug stubs to be deleted to silence ERC. (v1 agent 5 and v2 agent 5 both called this a BLOCKER. Wrong both times.)
  - 2× `power_pin_not_driven`: U9 (XC6206) Vin and H1 pin 1. Both are KiCad library artifacts — Q1 P-FET drain symbol-pin type is "passive" (not "power-output"), so KiCad doesn't see the +5V net as driven; H1 is a mounting-hole symbol with a bogus power pin. Real circuit is fine — agent 6 v2 traced wires explicitly (twin28xx.kicad_sch lines 14175/14425/33958) and confirmed +5V drives U9 V_in.
  - 9× `pin_to_pin` errors and 70× `pin_to_pin` warnings — many are symbol-library cosmetic; some real (diode-bridge symbol artifacts).
- **719 DRC violations** (down from 758 after your earlier fixes). Of those: ~509 cosmetic silk (199 silk_over_copper, 192 text_height, 118 silk_overlap), 46 lib_footprint_mismatch, 16 padstack_invalid, plus the electrical/mechanical issues called out in A1.

---

## C. NITS — improvements / cosmetic

- **VDDA ferrite missing** (demoted from v1 CRITICAL — see B2 note). AN4488 frames it as optional; low-priority improvement.
- **6 dangling top-level motor-phase labels** (debug stubs — delete to silence ERC).
- **2 zombie tracks** `/SPI2_MISO` and `/BOOT` (track_dangling).
- **Test point `/VCP` unconnected.**
- **DRVOFF default state**: confirm it boots in a safe (no-PWM) state before MCU comes up.
- **USB CC pull-down caps C1, C2 (47 pF) are DNP** — fine for stock USB-C device-mode. (The 49.9 Ω resistors that v1 thought were USB series resistors are actually on the SOx current-sense ADC filter path — v2 corrected this, no USB external Rs are needed since STM32G4 has internal D+ pull-up.)
- **ADC channel naming**: v1 said off-by-one. v2 verified **correct** against DS12288 Rev 1 Table 12. Removed.
- **VCC ampacity** for 8 A peak: v1 claimed it from IPC-2152, v2 couldn't verify against a primary-source IPC PDF. Probably fine given the pour geometry, but the master limit is the DRV8316 thermal envelope (B2) at ~1.5 A_RMS at 85 °C ambient — well below the trace ampacity question.
- DRV8316 datasheet URL in symbol property — wrong link.

---

## D. Analytical sims — answers to your questions (corrected)

### D1. "How much current can the board safely handle?"

**Verified directly from TI SLVSH07 datasheet.**

**Answer: ~1.3-1.6 A_RMS continuous per phase at 85 °C ambient. ~2.7-3.1 A_RMS at 25 °C ambient. 8 A peak transient is fine.** The user's 3-5 A_RMS target is **not safely achievable continuous on the standard 4-layer board at 85 °C ambient** without active cooling. At 25 °C ambient with max slew rate, ~3 A continuous is feasible.

Verified inputs:
- V_VM operating: 4.5/24/35 V min/nom/max (sec 7.3 p.6); abs max 40 V (sec 7.1 p.6).
- R_DS(on) HS+LS: typ 95 mΩ / max 120 mΩ at T_A=25 °C; typ 140 mΩ / max 185 mΩ at T_J=150 °C (sec 7.5 p.11).
- θ_JA: **25.7 °C/W** (sec 7.4 p.7, JEDEC 4-layer reference).
- P_CON (FOC) = **3 × I_RMS² × R_DS(on)** (sec 11.3.1 Table 11-1 p.85).
- P_SW = 3 × I_RMS × V_PK × t_rise/fall × f_PWM.

The v1 calc had two compounding errors: P_CON formula off by 2× (used 1.5×, should be 3×) and θ_JA off by 28% (used 33, should be 25.7 — but 25.7 is *better*, partially compensating). Net: v1 was ~50% optimistic. Corrected numbers are conservative.

### D2. IR-drop on power rails

VCC pour ampacity is not the binding limit; the DRV8316 thermal envelope is. At ~1.3-2 A_RMS the IR drop on VCC is negligible (< 50 mV).

### D3. Signal-integrity for fast signals

- **USB FS (12 Mbps)**: routes over solid In1.GND, no impedance issue at this rate. Good.
- **CAN-FD (5 Mbps)**: layer-fragmented diff pair (62 vs 42 segments, 11.5 mm length mismatch) — needs reroute as a clean diff pair on F.Cu over In1.GND. Key concern.
- **SPI to encoders**: short, low-rate. No SI concern.
- **HSE 12 MHz crystal**: load caps over-loaded by ~5 pF (D2/B2 above). Slow startup, small freq offset. Cosmetic-functional.

---

## E. Positive findings (sanity confirmations)

- **In1.Cu = clean solid GND plane** — verified by parser, zero routed segments. Textbook L2.
- **In2.Cu = split power + signals** — known constraint; B.Cu signals crossing splits is the SI risk.
- **18 unique GND vias under each DRV8316 EP** — exceeds TI's reference 16-via array (sec 11.2 p.84). Good thermal coupling.
- **MT6701 is correctly wired for I²C/SSI mode** — MODE pin hard-tied to +3.3V (verified `magnetic_encoder.kicad_sch` lines 2273/2193/2333/3129). Per Rev 1.8 §1.2 p.4 the chip supports both I²C and SSI on the same pins; master selects SSI by pulling NSS low. Both v1 agents had this wrong.
- **CAN choke U12 (ACT1210D-101) is populated**, not DNP. v1 false alarm — the X marks in the rendered schematic were the symbol's coupling glyph, not DNP markers.
- **DRV8316C charge-pump cap (C32 / C46 = 47 nF)** is correct for the C-variant. Confirmed.
- **DRV8316C VM bulk capacitance** (660 µF total per driver: 330 µF SMD + 330 µF THT) is generous.
- **BUCK power-OR architecture** (DRV buck OR'd with USB VBUS via Q1 P-FET) is clever and works in principle. Cold-start sequencing (#12) is the only catch.
- **Edge.Cuts is closed and clean** (pending the motor-shaft cutout question, #9).
- **SWD debug header / test points** confirmed accessible.
- **VDDA decoupling pairs (C25-C28) exist** (v1 missed this).

---

## F. Items I could NOT verify (open questions)

- DRV8316C VREF / ILIM (pin 37) connection — schematic-side trace not completed by agents. Visual check needed in `motor_driver.kicad_sch`. If floating in 6× PWM mode, current sensing breaks → FOC unusable. Cheap to verify.
- IPC-2152 8 A ampacity number — no IPC PDF available locally; agents cited the standard qualitatively only. Master thermal limit (D1) is binding anyway.
- ST DS12288 Rev 1 directly from ST — agents used a Farnell mirror PDF (same DS12288 content, doc-ID-verified). Fine in practice.
- Chipanalog CA-IF1044VD-Q1 full datasheet — LCSC anti-leech blocked; agent used TI TCAN1044V-Q1 SLLSF17D as functional twin. Some Chipanalog clones have NC on pin 5 instead of VIO; if your specific part is one of those, blocker #13 is moot. Verify the actual part-page on LCSC.
- SRV05-4A exact vendor — no LCSC code in BOM. Agent used DOWO datasheet as cross-reference. Check the BOM line.
- X322512MSB4SI Cm/C0 — used typical values for the frequency-pulling estimate (D2/B2). Order-of-magnitude correct.
- MT6701 PCB copper-keepout dimension — datasheet has no PCB-layout section. Sized #7 by magnet geometry (radius + ~1 mm guard).

---

## G. What I'd actually do, in order

1. **Fix the four PCB-edge-clearance issues** (#1-4): 5-minute moves. Fab will reject as drawn.
2. **Remove the 9 stacked duplicate vias** (#5): single edit kills 9 DRC errors.
3. **Move U16/U18 encoders to B.Cu** (#6) and **add magnet-axis copper keepouts on every layer** (#7). Reroute B.Cu signals away from encoder die (#8). This is the big layout change.
4. **Add motor-shaft cutouts to Edge.Cuts** (#9).
5. **Replace SMF30CA → SMF24CA** (#16) — same SOD-123FL footprint, drop-in.
6. **Hard-strap DRV8316 BUCK_SEL high** (#12) so 5 V rail comes up at 5 V on power-on.
7. **Add real 10 kΩ nFAULT pull-up** to +3.3V (#11), keep the LED.
8. **Re-do CAN termination jumper logic** (#10); **wire CAN_VIO to +3.3V** (#13); fix QWIIC pull-ups (#15).
9. **Verify DRV VREF/ILIM pin 37 cap exists and is 100 nF to AGND** (B2 / F).
10. **Pull DRV nSLEEP onto an MCU GPIO** if you ever want sleep-mode power saving.
11. Layout cleanups: re-pour around BK22 with denser GND stitching (B1); fix 12 starved-thermal connections; resolve M3 standoff conflict; reroute CAN-FD as clean diff pair on F.Cu over In1.GND.
12. Cosmetic ERC pass: delete dangling motor-phase labels, fix mirrored-on-back silk references, etc.
13. Optional: change C11/C18 to 20 pF for cleaner crystal startup; add VDDA ferrite if ADC noise floor matters.

After items 1-10 the board should be ready for first articles.

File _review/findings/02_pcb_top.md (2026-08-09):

# PCB Top-Side Review (v2 — primary-source verified)

Twin28xx dual BLDC, 76.95 x 36.93 mm, 4-layer.
Verified 2026-05-05 against:

- TI DRV8316C datasheet **SLVSH07** (Dec 2022), pages 5, 19, 82, 83, 84.
- Direct parse of `D:\gehub\twin28xx\twin28xx\twin28xx.kicad_pcb` (segments, vias, footprints, pad-net resolution after rotation).
- `D:\gehub\twin28xx\_review\drc.json` (KiCad 10.0.1 generated 2026-05-05 16:56).
- `D:\gehub\twin28xx\_review\stats.json`.
- Visual inspection of `D:\gehub\twin28xx\_review\datasheets\drv8316c_p84_layout_zoom.png` (rendered crop of TI Layout Example, sec 11.2).
- Visual inspection of `D:\gehub\twin28xx\_review\exports\layers\F.Silkscreen.pdf` and `D:\gehub\twin28xx\_review\exports\3d\top.png`.

Stackup re-confirmed from kicad_pcb lines 29-98:

```
F.Cu     35   um  (1 oz)
prepreg  210  um  NP-155F 7628, er 4.4
In1.Cu   15.2 um  (~0.5 oz)
core     1065 um  NP-155F core, er 4.43
In2.Cu   15.2 um  (~0.5 oz)
prepreg  210  um  NP-155F 7628, er 4.4
B.Cu     35   um  (1 oz)
```

`min_track_width = 0.16 mm`, `min_drill = 0.30 mm`, `min_track_clearance = 0.20 mm` per stats.json. No impedance control specified in `tuning_profiles`.

DRC totals (drc.json): 1 clearance, 18 hole_clearance, 7 copper_edge_clearance, 18 courtyards_overlap, 4 npth_inside_courtyard, 8 solder_mask_bridge, 12 starved_thermal, 16 padstack_invalid, 13 holes_co_located, 33 hole_to_hole, 2 track_dangling, 1 unconnected_items, plus 199 silk_over_copper / 192 text_height / 118 silk_overlap / 31 silk_edge_clearance / 46 lib_footprint_mismatch (cosmetic).

---

## BLOCKERS

### B1 — Bulk electrolytic pads C43 and C57 overhang the top board edge (0.000 mm clearance)

Re-verified from drc.json (`copper_edge_clearance`):

- `Pad 2 [VCC] of C43` at (109.000, 102.405) — actual edge clearance **0.0000 mm** to top Edge.Cuts segment (y=100.800).
- `Pad 2 [VCC] of C57` at (123.700, 102.405) — actual edge clearance **0.0000 mm**.

Footprint = `Capacitor_SMD_UWRL:CAP-SMD_BD10.0-L10.3-W10.3-LS11.0-R-RD` (kicad_pcb L18616). Both are EEEFT1H331GP 330 µF SMD electrolytics. The pad edges sit exactly on the route line; any V-cut/router tolerance will cut into copper.

**Action:** shift C43 and C57 ≥1 mm interior (decrease Y), or rotate 90° so the long axis is parallel to the edge.

### B2 — GND via 0.190 mm from J9 PHB1 motor pad

drc.json `clearance` (only one in the project): Via [GND] at **(136.500, 101.950)** → PTH pad 2 [/PHB1] of J9 at **(135.750, 103.149)**, actual 0.1895 mm vs 0.2000 mm rule. At 24 V this is electrically fine but with ±0.05-0.10 mm drill registration the GND drill can shave the J9 pin barrel.

**Action:** move via ≥0.3 mm or shift J9.

### B3 — J5 / J1 GND pads 0.175-0.196 mm from bottom Edge.Cuts

drc.json `copper_edge_clearance`, edge segment at y=137.725:

- Pad 5 [GND] of J5 (144.200, 136.400) — 0.1750 mm
- Pad 6 [GND] of J5 (138.900, 136.400) — 0.1750 mm
- Pad 4 [GND] of J1 (137.099, 136.529) — 0.1961 mm
- Pad 5 [GND] of J1 (132.498, 136.529) — 0.1961 mm

Same family as B1 but bottom-side connectors.

**Action:** shift J5 and J1 ≥0.3 mm up.

### B4 — U5 (TVS) GND pad 0.165 mm from top Edge.Cuts (newly flagged)

Not called out in the prior review. `Pad 2 [GND] of U5 on F.Cu` at (115.600, 101.665), edge clearance **0.1649 mm** to top Edge.Cuts at y=100.800 (drc.json `copper_edge_clearance`). Same fab risk family as B1/B3.

**Action:** move U5 ≥0.4 mm interior.

### B5 — 9 stacked GND vias on U15 EP and U7 (drilled holes co-located, real fab error)

Re-grepped from .kicad_pcb: 26 raw `(via ...)` entries inside the U15 EP bounding box but only **18 unique XY positions** — 8 positions have **two stacked vias** (identical XY, identical 0.45/0.30 size/drill, identical net "GND"). Coordinates (drc.json `holes_co_located`):

```
(91.750, 108.750), (91.750, 111.750), (93.750, 108.750), (93.750, 111.750),
(92.750, 108.750), (92.750, 111.750), (90.750, 108.750), (90.750, 111.750)
```

This is genuine duplicate via geometry — the file has two `(via ...)` blocks at each of these eight positions. Plus one more pair at (115.600, 132.600) under U7. Total 9 stacked-via DRC errors. The fab will drill each hole twice (or fail outright). The U14 EP does **not** have this problem (18 unique positions, 18 vias).

**Action:** delete the duplicate via at each of the 9 listed XYs. This single fix closes 9 of the 13 `holes_co_located` errors.

---

## CRITICAL

### C1 — DRV8316C ceramic decoupling caps too far from VM / CPH-CPL pins

**Primary source — TI DRV8316C datasheet, page 5 ("Pin Functions"):**
> VM ... bypass to PGND with two 0.1-µF capacitors (for each pin) plus one bulk capacitor rated for VM.
> CP ... Connect a X5R or X7R, 1-µF, 16-V ceramic capacitor between the CP and VM pins.
> CPH/CPL ... Connect a X5R or X7R, 47-nF, ceramic capacitor between the CPH and CPL pins.

**Primary source — TI DRV8316C datasheet, page 83 (sec 11.1 Layout Guidelines):**
> Small-value capacitors such as the charge pump, AVDD, and VREF capacitors should be ceramic and placed closely to device pins.

The datasheet does not state a numeric distance, but the TI Layout Example (sec 11.2, page 84, rendered as `drv8316c_p84_layout_zoom.png`) shows the 0.1 µF VM caps, the 47 nF CPH/CPL fly cap and the AVDD cap **immediately adjacent** to the package, all within ~1× package-pin pitch (≈ 1-2 mm of the relevant pin).

On Twin28xx I measured (after 90° rotation transformation of pad-local to global coordinates):

| Cap | Value (verified) | Function | Position | Nearest VM pin | Nearest CPH/CPL pin |
|---|---|---|---|---|---|
| **C36** | 0402 100 nF X7R 50 V (CL05B104KB54PNC) | U14 VM bypass (CVM1) | (139.0, 107.527) | **7.13 mm** | 6.41 mm |
| **C32** | 0603 47 nF X7R 50 V (CL10B473KB8NNNC) | U14 CFLY (CPH-CPL) | (140.5, 110.277) | 7.50 mm | **7.40 mm** |
| **C50** | 0402 100 nF X7R 50 V (CL05B104KB54PNC) | U15 VM bypass | (95.5, 107.527) | **6.92 mm** | 6.18 mm |
| **C46** | 0603 47 nF X7R 50 V (CL10B473KB8NNNC) | U15 CFLY | (97.0, 110.277) | 7.26 mm | **7.15 mm** |

VM pin row of U14 is at global (133.100, 111.527 / 112.027 / 112.526) for pins 9/10/11 respectively, and CPH/CPL at (133.100, 110.527 / 110.027). VM pin row of U15 is at (89.850, 111.5-12.5).

These caps are 6-8 mm from the relevant device pins. TI's reference layout puts them within ~2 mm. At 6-8 mm the loop inductance to the VM pin is roughly 5-10 nH, which at fast switching transitions (8 A peak, ~50-200 V/µs slew) gives 0.4-2 V loop voltage, partially defeating the purpose of the high-frequency bypass.

**Note on the prior review's "C36 ... 3.4 mm from U14 centre" claim:** that number was distance to *EP center* (135.5, 110.277). TI's guidance is for distance to *device pins*, not EP. Re-stated correctly above.

**Action:** move C36, C32 next to U14 VM/CPH/CPL pins (≤2 mm from the pin row at x=133.1). Same for C50/C46 next to U15 (≤2 mm from x=89.85). This may require relocating the bulk cap cluster (C40/41/42 and C37/38/39) outward.

### C2 — DRV8316C EP via count vs. TI recommended layout (re-verifying the prior claim)

**Prior claim being re-verified:** "~22 thermal vias under each DRV8316 EP — well above the 9-12 spec."

**TI DRV8316C datasheet, page 83 sec 11.1 Layout Guidelines, full quote of relevant passage:**
> The device thermal pad should be soldered to the PCB top-layer ground plane. Multiple vias should be used to connect to a large bottom-layer ground plane. The use of large metal planes and multiple vias helps dissipate the I²×RDS(on) heat that is generated in the device.
>
> To improve thermal performance, maximize the ground area that is connected to the thermal pad ground across all possible layers of the PCB. Using thick copper pours can lower the junction-to-air thermal resistance and improve thermal dissipation from the die surface.

**The datasheet text does not give a numerical via count.** The "9-via minimum" or "9-12 spec" referenced in prior reviews is **not present in SLVSH07** — that number appears to have been confabulated or copied from a different TI part. The only quantitative guidance is the **Layout Example figure (sec 11.2, page 84)**, which I rendered and visually counted: TI's reference layout shows a **4 × 4 = 16-via array** under the EP.

**Actual via count under each EP** (parsed from .kicad_pcb, dedupe by XY, GND net only, within ±2.85 mm box of EP center):

| Driver | EP center | Unique GND via positions | Raw via count | Notes |
|---|---|---|---|---|
| U14 | (135.500, 110.277) | **18** | 18 | Clean. Exceeds the 16 in TI's example. |
| U15 | (92.250, 110.277) | **18** | 26 | 8 stacked duplicates — see B5. The unique-position count matches U14. |

Via specs: **0.45 mm pad / 0.30 mm drill**, F.Cu↔B.Cu through. Consistent with TI's "multiple vias" guidance.

**Verdict:** the *number* of unique vias (18 each) exceeds TI's reference example (16) and is acceptable. The 16 vs 18 difference is not material. The U15 stacked-via fault (B5) is the actual problem — it's a fab issue, not a thermal one.

**Correction to prior review:** drop the "9-via minimum" claim. Replace with: "TI's layout example (sec 11.2) uses a 4×4 array; Twin28xx has 18 unique via positions per EP, exceeding TI's example."

### C3 — Twelve `starved_thermal` connections to GND zone

drc.json (re-verified, list unchanged from prior review):

- J5 pin 1 (CAN GND) at (140.050, 132.800)
- U9 pin 1 (LDO GND) at (85.050, 129.465)
- C23 pin 2 (114.839, 133.117)
- C8 pin 2 (87.000, 128.750) — 5 V deco
- C4 pin 1 (84.680, 128.200) — 5 V
- **X1 pin 2 (125.875, 119.650) and pin 4 (124.125, 121.850)** — crystal GND, clock-stability concern
- C60 pin 1 (98.480, 118.500) — 3.3 V deco at U18 encoder
- C14 pin 1 (129.475, 126.500)
- U7 pin 63 (121.311, 126.742) — STM32 VSS pad
- C59 pin 1 (137.780, 117.700) — 3.3 V near CAN
- R5 pin 2 (116.890, 101.600)

Zone min_spoke = 2; these have actual_spoke = 1. Single-spoke thermal relief has ~2× the thermal resistance and is mechanically weak on rework. STM32 VSS and crystal pins matter most.

**Action:** widen `thermal_bridge_width` (currently 0.5 mm) on the In1.GND zone, or hand-place a second GND via beside each affected pad to force the second spoke.

### C4 — H1 / H4 / H7 / H10 mounting-hole footprints generate 18 hole_clearance + 8 mask-bridge errors

Verified by reading the H1/H4/H7/H10 footprints (`MountingHole:MountingHole_3.2mm_M3_Pad_Via`) directly from kicad_pcb:

- Each has **9 thru-hole pads** (1 center + 8 stitching at 2.4 mm radius — kicad_pcb L23666-style pad listing). Pad type is `thru_hole` (not `via`); shape circle.
- The 8 stitching PTH pads have NPTH-of-Hxx (the stacked SMT standoff `Mechanical:SMD_BD5.6-D3.6` with 3.6 mm NPTH) within their hole-clearance window. Resulting DRC: at H10/H12 alone, 9 hole_clearance violations (one for the centre PTH-NPTH pair at 0.000 mm, plus 8 for the stitching pads at 0.100 mm). Total over H1/H4/H7/H10 = 18 hole_clearance + 4 holes_co_located + 4 npth_inside_courtyard + 8 solder_mask_bridge.

(Prior review said "33 hole-clearance" — current DRC shows 18; difference is because KiCad 10 reports `hole_to_hole` (33) and `hole_clearance` (18) as separate counts. Total mounting-related errors are still ~38 ignoring duplicates.)

**Action:** widen the stitching ring to ≥2.0 mm radius beyond the M3 hole edge so it doesn't conflict with the 3.6 mm standoff NPTH, or replace the 8 stitching PTH pads with a single GND pour + GND vias outside the standoff body.

### C5 — Eighteen courtyard overlaps in the central cluster (re-verified)

drc.json `courtyards_overlap` list (all 18 confirmed):

- C49/C48 (1.75 mm pitch, 0805) — same for C34/C35
- C28/C26, C27/C25 (the 4-cap diamond around U7 NW corner)
- R28/R21, R27/R21, R23/R24 — 0402 quartet collisions
- TP19/R12, TP21/R13, TP26/C5 — test points on top of resistors
- C8/C7 (1.86 mm pitch)
- C39/H10, C38/H10, C37/H10 — VCC bulk caps butted into the M3 hole
- U6/U19, U18/C60 — IC and adjacent decoupling cap touching
- C1/U19, R30/D3

Pick-and-place is OK; rework with a 2-3 mm conical iron tip will not fit.

### C6 — Two zombie tracks and one orphan TP (re-verified)

drc.json `track_dangling`:
- Track [/SPI2_MISO] on B.Cu, length 1.000e-06 mm at (100.840, 128.160)
- Track [/BOOT] on B.Cu, length 0.2982 mm at (131.640, 125.860)

drc.json `unconnected_items`: Pad 1 [/VCP] of TP46 at (103.473, 111.130) plus a 4 mm orphan /VCP F.Cu segment.

**Action:** delete all three.

### C7 — CAN-FD diff pair fragmented and length-mismatched

Re-verified by parsing all `(segment ... (net "X"))` blocks of the .kicad_pcb (1859 segments total):

| Net | F.Cu | In2.Cu | B.Cu | Total segments | Total length |
|---|---|---|---|---|---|
| /CAN_H | 32 | 11 | 19 | **62** | **123.88 mm** |
| /CAN_L | 22 | 6 | 14 | **42** | **112.37 mm** |

**11.51 mm length mismatch** between the two diff lines. At 5 Mbps CAN-FD that's roughly 60-80 ps of intra-pair skew (electrical length on FR4 ≈ 6-7 ps/mm), tolerable for the bit period but couples to common-mode noise and unbalances the receiver thresholds. Combined with the In2.Cu split-plane region under part of the route (see `04_pcb_inner.md` B-1, B-2), this is a real EMC liability.

**Action:** route CAN_H and CAN_L as a clean diff pair on a single layer (preferably F.Cu over solid In1.Cu GND), match lengths within 1 mm.

### C8 — USB D+/D- length mismatch ~2 mm, no impedance control

Re-verified:

| Net | F.Cu | In2.Cu | B.Cu | Total | Length |
|---|---|---|---|---|---|
| /D+ | 21 | 0 | 0 | 21 | **18.71 mm** |
| /D- | 20 | 0 | 0 | 20 | **20.67 mm** |

Both stay on F.Cu (good — In1.Cu solid GND is the reference plane below at 210 µm dielectric, per `04_pcb_inner.md`). Length mismatch ~1.95 mm, well within USB 2.0 FS tolerance (~5 mm). USB FS will work without controlled impedance.

`tuning_profiles` in twin28xx.kicad_pro is unset — no impedance constraint defined. With 0.20 mm trace width on 0.21 mm prepreg er≈4.4 to In1.Cu, single-ended Z₀ is approximately 65-70 Ω; coupled differential Z_diff is approximately 90-100 Ω depending on gap (could not measure gap without rendering). This is acceptable for FS USB.

### C9 — Crystal X1 ~10 mm diagonal from STM32 OSC pins, plus 2 starved_thermal

X1 (X322512MSB4SI, 4-pad SMD crystal) at (125.0, 120.75), 90°. U7 STM32G473RB at (115.0, 125.028), -135° (LQFP-64 rotated 45°). Center-to-center distance ≈ 10.9 mm. OSC_IN/OSC_OUT trace length ~8-12 mm running across mid-board F.Cu zone fills.

Per ST AN4488 §3.3 (Clock System), the crystal should be placed close to the OSC pins. Twin28xx is at the edge of typical guidance. Combined with the two starved_thermal connections on X1 pins 2 and 4 (see C3), the HSE oscillator is the most sensitive node on the design.

For a 12 MHz HSE this is functional but tight. Per master findings D3, the load caps (30 pF) match the X322512MSB4SI 20 pF datasheet load correctly. Verify visually on F.Cu: (a) OSC traces are guarded by GND on both sides, (b) load-cap returns connect with 2 GND vias right at the crystal, (c) no PHA*/PHB*/PHC* gate-drive nets cross within 2 mm.

### C10 — VCC bulk cap cluster overlaps H10 courtyard (re-verified)

drc.json: courtyards C39 / C38 / C37 each overlap H10. All three caps are at x=145.250 (102.65 / 104.64 / 106.60). H10 M3 mounting hole is at (150.057, 104.250). Combined with B1, the upper-right power-input region is over-packed.

**Action:** pull the right cluster ≥0.5 mm clear of H10.

---

## NITS

### N1 — Silkscreen pollution (199 silk_over_copper, 192 text_height, 118 silk_overlap, 31 silk_edge_clearance)

Visual inspection of `D:\gehub\twin28xx\_review\exports\layers\F.Silkscreen.pdf` confirms the central area (around U7/X1/encoders) is essentially unreadable — refdes stack on top of pads and on each other. After placement is locked, hide refdes for parts smaller than 0805 in this region. Cosmetic.

### N2 — Footprint-symbol-mismatch warnings (46 lib_footprint_mismatch + 1 lib_footprint_issues)

Cosmetic. Set the footprint property in the symbol or right-click each footprint and "Update with override footprint".

### N3 — 16 padstack_invalid on H3/H6/H9/H12 corner pads

Custom pad shapes resolve to multiple polygons. Cosmetic; gerbers rasterize fine.

### N4 — F.Paste apertures

Visual inspection of `D:\gehub\twin28xx\_review\exports\layers\F.Paste.svg`: the DRV8316 EP shows a single solid 5.7 × 5.7 mm aperture. For best yield TI typically recommends splitting the EP paste into a grid (typical 4×4 or 5×5 with ~50-70 % paste coverage) to prevent solder volcano + IC float during reflow.

> Note: this is **not** stated in DRV8316C SLVSH07 — it is general industry practice for QFN/VQFN with large EPs (e.g. IPC-7093). I am citing it as a process-level recommendation, not a TI requirement.

### N5 — F.Mask bridges (8) all under SMT standoffs

All 8 `solder_mask_bridge` errors map to the H1/H4/H7/H10 stack with their corresponding standoffs H3/H6/H9/H12. Same root cause as C4.

### N6 — Encoders U16 (135.0, 120.028) and U18 (95.0, 120.028) on F.Cu

Per master findings A2 #11, the encoders should be on B.Cu under the rotor magnets. This is a top-level design-intent issue and is logged there; not re-litigated here. Magnet-to-die spacing must include any standoff/lid clearance.

### N7 — VCC pour ampacity (cannot be fully verified without IPC-2152 source)

The prior review claimed "VCC pour ... provides adequate 8 A ampacity" citing IPC-2152. **I do not have the IPC-2152 PDF to quote directly**, and per the verification rules I cannot cite a third-party blog. I can only verify the geometry from the .kicad_pcb:

- VCC delivered via two zones on F.Cu (`VCC_F` priority 6, `VCC1` priority 7) plus one multi-layer pour on B.Cu+In2.Cu (`VCC_IN2` priority 8).
- Zone `min_thickness = 0.25 mm`; outer pour appears 3-5 mm wide visually in the F.Cu rendering between BK22 (J11/J12) and the bulk caps and DRV inputs (verified by reading the `(polygon (pts ...))` of `VCC_F` at kicad_pcb L65898).
- Phase nets PHA1/PHB1/PHC1/PHA2/PHB2/PHC2 are F.Cu pours (zones, not segments) with min_thickness = 0.25 mm.
- F.Cu = 35 µm (1 oz), confirmed in stackup.
- 0 motor-phase or VCC traces routed on inner copper (`segment` count for /PHx* nets = 0 across all layers; only zones).

**Without IPC-2152 quoted directly, I cannot independently restate the 8 A ampacity figure.** What I can confirm from the stackup and from `04_pcb_inner.md` (verified independently): VCC is also poured on B.Cu+In2.Cu, so total cross-section is roughly 1 oz F.Cu + 0.5 oz In2.Cu + 1 oz B.Cu in parallel where these pours overlap. For VCC current return through electrolyte the limiter is more likely the necks at via fields than the bulk pour. This is not a primary-source verifiable claim — flagged as **unverified**.

Per master findings D1, the binding limit is DRV8316C junction temperature (1.5-2 A RMS at 85 °C), not trace ampacity, so this is not a fab blocker even if IPC-2152 numbers were tighter than the prior review claimed.

### N8 — 25 F.Cu footprints have Reference text on B.SilkS (mirrored) — count corrected

Programmatic check on all 205 footprints: footprint primary `(layer "F.Cu")` AND its `Reference` property `(layer "B.SilkS")` with `(justify mirror)`:

```
R28, C51, U4, C40, C58, C44, C52, C39, C38, U5, C42, R27, R23, R24,
C56, C43, C41, C54, C57, LED1, R21, C37, C55, C53, R5
```

That's **25 footprints**, not 26+. The bottom silk will print component reference labels for parts that don't physically exist on the back side. Cosmetic but confusing in assembly.

**Correction to prior review:** count was 25, not "26+".

**Action:** in KiCad, select these and move Reference text back to F.SilkS.

### N9 — 13 holes_co_located (9 of these are the U15 stacked vias from B5)

Of the 13 `holes_co_located` errors:
- 9 are duplicate vias on U15 EP and one under U7 — actual fab errors (B5).
- 4 are the H1/H4/H7/H10 + standoff stacks — by-design (C4).

After fixing B5 the count drops to 4, all explained.

---

## Notes / positives

- **Edge.Cuts** — closed rectangle (76.525, 100.800) → (153.475, 137.725) with 3.4 mm rounded corners. No zero-length segments, no degenerate edges. Good.
- **C32/C46** = 47 nF X7R 50 V (CL10B473KB8NNNC, 0603) — matches DRV8316C datasheet sec 8.3 Table 8-1 CFLY exactly: "X5R or X7R, 47-nF". (Prior briefing of "22 nF" was wrong.)
- **C36/C50** = 100 nF X7R 50 V (CL05B104KB54PNC, 0402) — matches CVM1 in Table 8-1: "X5R or X7R, 0.1-µF". The cap values are correct; the placement is the issue (C1).
- **C40/C41/C42** = 10 µF X5R 50 V (GRM21BR61H106KE43L, 0805) — matches CVM2: "≥ 10-µF, voltage rating ≥ 2× operating (i.e. ≥ 48 V)". 50 V rating meets the spec.
- **C43/C57** = 330 µF SMD electrolytic plus C44/C58 = 330 µF radial THT — large bulk per sec 10.1 ("Bulk Capacitance"). Value fine; placement (B1) is the issue.
- **VM/charge-pump/AVDD** — TI Layout Example sec 11.2 page 84 visible in `drv8316c_p84_layout_zoom.png`: shows 4×4 = 16-via EP array, ceramics directly adjacent to package. Twin28xx has 18 vias under each EP — exceeds the example.
- **In1.Cu = solid GND** (per `04_pcb_inner.md`) — textbook L2 placement, ideal F.Cu signal reference.
- **Component density** 37 (front) vs 9.6 (back) per stats.json — heavily front-loaded, but back has GND copper area 2614 mm² to share heat.
- **No motor-phase or VCC routed on inner copper** — keeps the high-current paths on 1 oz outer layers (smart given 0.5 oz inner copper).
- **Test points** (TP1-TP47) accessible on F.Cu, 1.0 mm SMD pads — fine for needle probes; some courtyard collisions (C5).

---

## Suggested fix order

1. **B5** — delete the 9 stacked duplicate vias (8 on U15 EP + 1 under U7). Single-edit fix that closes 9 DRC errors and prevents fab drilling failure.
2. **B1** — move C43, C57 inward by ≥1 mm (or rotate 90°).
3. **B4** — move U5 ≥0.4 mm interior.
4. **B3** — shift J5 / J1 ≥0.3 mm up.
5. **B2** — move GND via at (136.5, 101.95) or shift J9.
6. **C1** — move C36/C32/C50/C46 to within 2 mm of the relevant DRV8316 pins; relocate C40/41/42 outward to make room.
7. **C4** — widen the H1/H4/H7/H10 stitching ring to ≥2 mm beyond the standoff NPTH.
8. **C7** — re-route CAN-FD diff pair on F.Cu over solid In1.GND, length-match within 1 mm.
9. **C3** — widen `thermal_bridge_width` or hand-place 2nd GND vias on the 12 starved_thermal pads (priority X1 pins 2 & 4, then U7 pin 63).
10. **C6** — delete /SPI2_MISO zombie, /BOOT stub, /VCP orphan.
11. **C5, C10** — pull courtyard-overlapping clusters apart by ≥0.5 mm where rework matters.
12. **N8** — move the 25 mirrored Reference texts back to F.SilkS.
13. **N1** — silk polish: hide refdes for sub-0805 parts in the central cluster.

---

## Corrections to prior version

| Prior claim | Status | Correction |
|---|---|---|
| "~22 thermal vias under each DRV8316 EP — well above the 9-12 spec" | **Wrong (no such spec exists)** | TI SLVSH07 sec 11.1 says "Multiple vias should be used" with no number. Sec 11.2 Layout Example (page 84) shows a 4×4 = 16-via array. Actual unique-position count is 18 per EP, not 22 (raw count of 22 included the duplicates flagged in B5). U14 has 18 unique; U15 has 18 unique + 8 duplicates = 26 raw. |
| "C36 ... 3.4 mm from U14 centre" | **Misleading** | 3.4 mm was distance to EP center; distance to nearest VM pin is **7.13 mm**. Same applies to C50. Now flagged as CRITICAL C1. |
| "VCC pour ... provides adequate 8 A ampacity" (citing IPC-2152) | **Cannot independently verify** | IPC-2152 PDF not in `_review/datasheets/`. Geometry confirmed (zones on F.Cu, B.Cu, In2.Cu; min_thickness 0.25 mm). Flagged as N7 — unverified, but per master findings D1 the binding constraint is DRV8316 junction temperature, not VCC ampacity. |
| "26+ F.Cu footprints have Reference text on B.Silkscreen" | **Off by one** | Programmatic count = exactly **25**. Listed by designator in N8. |
| "33 hole-clearance errors at H1/H4/H7/H10" | **KiCad 10 split** | Current DRC reports 18 `hole_clearance` + 33 `hole_to_hole` + 4 `holes_co_located` + 4 `npth_inside_courtyard` for the same physical situation. Total mounting-related errors ≈ 38 (was reported as 33 in older KiCad). |
| 12 starved_thermal | Re-verified | List unchanged from prior review. |
| New finding: **B4 — U5 GND pad 0.165 mm from top edge** | Newly flagged | Not in prior review. Confirmed in drc.json `copper_edge_clearance`. |
| New finding: **B5 — 9 stacked vias (real fab error)** | Newly flagged | Prior review attributed all 13 `holes_co_located` to mounting holes; in fact 9 of them are duplicate `(via ...)` blocks on U15 EP and U7 — distinct fab-blocking issue. |
| New finding: **C1 — DRV8316C ceramic decoupling caps too far from VM/CPH/CPL pins** | Newly flagged | Prior review checked distance to EP center (3.4 mm) and called it "adequate". Distance to actual VM pins is 7+ mm — too far per TI sec 11.1. |
| New finding: **C8 — USB D+/D- length mismatch ~2 mm** | Numerically verified | Prior review said "Length-matching not verified numerically." Now measured: D+ = 18.71 mm, D- = 20.67 mm. Acceptable for USB FS. |
| Bulk-cap value verification | Confirmed | C36/C50 = 100 nF, C32/C46 = 47 nF, C40/41/42 = 10 µF, C43/57 = 330 µF SMD electrolytic, C44/58 = 330 µF radial THT. All match TI Table 8-1 recommendations. |

---

## Primary-source citations

- **TI DRV8316C datasheet SLVSH07 (Dec 2022)** — `D:\gehub\twin28xx\_review\datasheets\DRV8316C_TI.pdf`:
  - Page 5 (Pin Functions table) — VM bypass cap requirement, CFLY 47 nF, CCP 1 µF, AVDD 1 µF.
  - Page 19 (sec 8.3, Table 8-1) — full external component list with values and ratings.
  - Page 83 (sec 11.1 Layout Guidelines) — quoted in C1 and C2.
  - Page 84 (sec 11.2 Layout Example) — visual 4×4 EP via grid; rendered to `D:\gehub\twin28xx\_review\datasheets\drv8316c_p84_layout_zoom.png`.
  - Page 6 (sec 7.1, 7.3) — operating range 4.5-35 V, abs max 40 V.
- **ST AN4488** — referenced in C9 for crystal placement guidance. Not held locally; cited only qualitatively.
- **IPC-2152** — referenced by prior review for ampacity. **Not held locally**, so no numerical claim from this standard appears in this re-verified review (see N7).

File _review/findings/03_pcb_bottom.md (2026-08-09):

# PCB Bottom-Side Pre-Fab Review (v2) — `twin28xx.kicad_pcb`

Reviewed: 2026-05-05 (re-do with primary-source verification)
Source: `D:\gehub\twin28xx\twin28xx\twin28xx.kicad_pcb`
Stats: 76.95 × 36.925 mm, 4-layer, 1.6167 mm thick (`_review/stats.json`).
Per `stats.json`: front-density 37.04 %, back-density 9.59 %, **0 components** on the back layer (`components.smd.back = 0`, `components.tht.back = 0`, `components.unspecified.back = 0`).

---

## Corrections to prior version (`v1_archive/03_pcb_bottom.md`)

| # | Prior claim | Correction (with primary-source citation) |
|---|---|---|
| 1 | "Magnet → encoder die distance is now FR4 (1.62 mm) + QFN-16 package thickness (~0.85 mm) ≈ 2.5 mm. MT6701 datasheet operating range is ~1–3 mm but signal magnitude … degrades sharply past ~2 mm." | **Wrong on both numbers.** MT6701 datasheet (MagnTek Rev.1.5, 2021.03 / Rev.1.8, 2022.12) §5 "Magnetic Input Specifications", page 8, parameter **AG (Air Gap, Magnetic to IC Surface Distance)**: **Min 0.5 mm, Typ 1.0 mm, Max 2.0 mm**. The "operating range" is 0.5–2.0 mm, not 1–3 mm. QFN-16 package thickness from §9.2 (page 33), parameter **A**: **0.700–0.800 mm** (max), not 0.85 mm. The realistic stack-up is 1.617 mm FR4 + ~0.75 mm package ≈ **2.37 mm**, which **exceeds the datasheet AG_max (2.0 mm) by ~0.37 mm — the part is operating *outside its specified magnetic-input range*, not "at the upper limit."** |
| 2 | "/SPI1_MISO 0.16 mm at (93.25, 117.41)→(97.41, 117.41) within ±2.5 mm of U18 die" | Re-measured: closest distance from U18 center (95.000, 120.0275) to the /SPI1_MISO segment is **2.621 mm** (just outside 2.5 mm). The /TIM8_CH3N segment is 2.028 mm. The /SPI1_MISO concern as stated overshot by ~0.1 mm. Real worst-offenders (re-listed in B3): /TIM8_CH2 at **0.617 mm** (clipping the courtyard) and /TIM8_CH3 at 1.819 mm. |
| 3 | "no keepout/anti-pad is defined under the MT6701 die" | True, **but verify the KiCad construct**. The two `(keepout …)` blocks at lines 66599 and 82824 in `twin28xx.kicad_pcb` are *placement-rule areas* (`auto-placement-area-/motor_driver/`, `auto-placement-area-/motor_driver1/`) with `tracks/vias/pads/copperpour/footprints` all set to `allowed`. They are NOT copper exclusions and do nothing to clear the GND pour. Confirmed there is no `(rule_area)` or copper keepout anywhere in the file. |
| 4 | "MT6701/AS5048 designs is a circular copper keepout of at least 5–6 mm diameter" | The MT6701 datasheet (Rev 1.5 / 1.8) **does not specify a copper keepout** anywhere in the document. There is no mention of "keepout", "PCB layout", or copper near the magnetic path. The datasheet only specifies AG and Bpk as measured at the IC surface. The "5–6 mm keepout" recommendation is **not from MagnTek's datasheet** — sourced rule of thumb only and removed from this review. |
| 5 | "MT6701 QFN-16 package thickness ~0.85 mm" | MT6701 §9.2 gives **A = 0.700–0.800 mm** (typ ~0.75 mm), not 0.85 mm. |

The two trace-routing and GND-fill structural findings (B2, B3) and the no-cutout finding (C1) survive intact. The headline "wrong-side encoder" finding (B1) is *strengthened*, not weakened: the gap is **above** the datasheet maximum, not at the limit.

---

## Datasheet citations (primary sources, this review)

- MT6701 — MagnTek MT6701 Hall-Based Angle Position Encoder Sensor.
  - Rev.1.5, 2021.03 (English, 36 pp). Mirrored at https://uploadcdn.oneyac.com/attachments/files/brand_pdf/magntek/F3/CA/MT6701QT-STD.pdf — local copy at `D:\gehub\twin28xx\_review\datasheets\MT6701_alt_MT6701QT-STD.pdf`. The footprint's own `Datasheet` property in `twin28xx.kicad_pcb` (lines 6647 and 13158) references **Rev.1.5**, so this is the working revision.
  - Rev.1.8, 2022.12 (Chinese, 36 pp). Direct from MagnTek: https://www.magntek.com.cn/upload/pdf/202312/MT6701_Rev.1.8_中文版.pdf — local copy at `D:\gehub\twin28xx\_review\datasheets\MT6701_Rev1.8.pdf`. Spec values for AG and Bpk are identical between Rev 1.5 and Rev 1.8.
  - **§5 "Magnetic Input Specifications" / "外加磁场参数", page 8/9** — verbatim:
    - `Bpk` (Magnetic Input Field Amplitude, "Measure at the IC Surface"): **Min 200, Max 1,000, Unit Gauss**.
    - `AG` (Air Gap, "Magnetic to IC Surface Distance"): **Min 0.5, Typ 1.0, Max 2.0, Unit mm**.
    - `Dmag`: typ 6.0 mm; `Tmag`: typ 2.5 mm; `DISP` (off-axis misalignment): max 0.3 mm.
  - **§1.2 / Figure 2 "Pin Configuration for QFN-16 Package", page 4** — Sensing Center is at the geometry center of the package (annotation "Sensing Center at Geometry Center" on top-view diagram).
  - **§2 "Functional Diagram" + Figure 3, page 5** — "uses advanced magnet sensing technology to sense the magnetic field distribution across the surface of the chip … delivers a voltage representation of the magnetic field at the surface of the IC." Confirms the AG reference plane is the chip top surface (under mold compound, package-top side).
  - **§9.2 "QFN-16 Package", page 33** — package outline:
    - `A` (overall height): Min 0.700, Max 0.800 mm.
    - `A1` (standoff): 0.000–0.050 mm.
    - `D × E` (body): 2.900–3.100 mm × 2.900–3.100 mm.
    - `D1 × E1` (EP exposed pad): 1.600–1.800 × 1.600–1.800 mm.
    - `e` (pitch): 0.500 mm REF; `b` (lead width): 0.180–0.300 mm.
  - **What the datasheet does NOT cover**: through-PCB sensing, copper keepout, ground-plane attenuation, or eddy-current effects from intervening copper. There is no PCB-layout / app-note section in this datasheet. Any claim about copper keepouts under the encoder is therefore **NOT** datasheet-supported.

---

## BLOCKERS

### B1 — MT6701 magnetic encoders are placed on the WRONG side of the board (F.Cu instead of B.Cu) — sense gap exceeds AG_max

The README states the motors mount on the back of the PCB; the rotor's diametric magnet is therefore on the back side. The MT6701 sensing center is at the package-top (`§1.2`, Figure 2 "Top View"), and AG is measured from the magnet to the IC surface (`§5`).

What the file actually shows:

| Designator | Footprint | Layer | Center (mm) | Source line |
|---|---|---|---|---|
| U18 | `Package_DFN_QFN:QFN-16-1EP_3x3mm_P0.5mm_EP1.7x1.7mm` | **F.Cu** | (95.000001, 120.0275) | `twin28xx.kicad_pcb` 6618–6624 |
| U16 | same | **F.Cu** | (135.000001, 120.0275) | `twin28xx.kicad_pcb` 13129–13135 |

Pads of both parts are on `F.Cu` / `F.Mask` / `F.Paste`; silk, courtyard, and fab on `F.SilkS` / `F.CrtYd` / `F.Fab`. Independently confirmed by `stats.json`: `components.smd.back = 0`. Bottom-side `B.Paste`, `B.Courtyard`, and `B.Fab` SVG exports contain only board-outline plus drill apertures.

**Sense-path geometry** (encoder on F.Cu, magnet on the rotor below B.Cu):

| Stack-up element | Thickness (mm) | Source |
|---|---|---|
| FR4 board (full thickness) | 1.6167 | `stats.json` `board.board_thickness` |
| QFN-16 package height (max) | 0.800 | MT6701 §9.2 (Rev 1.5 page 33) |
| QFN-16 package height (typ) | ~0.750 | midpoint of `A = 0.700–0.800` |
| (`A3` die-paddle thickness 0.203 REF; the sensing element is at die top surface internal to the package) | — | MT6701 §9.2 |

**Magnet → IC-surface distance**: 1.617 + (typ 0.75) ≈ **2.37 mm** (with worst-case package: 1.617 + 0.800 = **2.42 mm**).

**MT6701 AG_max from §5 = 2.000 mm.** The realised gap is **0.37–0.42 mm above the datasheet maximum** — the part will be operated outside its specified magnetic-input range. Bpk at the IC surface will fall well below 200 Gauss for any normal NdFeB diametric magnet (a 6×2.5 mm N35 puck typically gives ~150–250 G at 2 mm and continues falling steeply with z). Outcomes likely: marginal or asserted "Bpk-too-weak" status flag (`Mg[3:0]` field, MT6701 §7 / register-map page 27), elevated angle noise, large temperature drift (`TCmag1 = -0.12 %/°C` for NdFeB, §5). Not waivable in firmware; this is a magnetic-air-gap deficiency.

**Fix**: move U16 and U18 to B.Cu (mirror about the board), or change the mechanical scheme so the magnet sits on the F.Cu side at ≤2.0 mm AG.

### B2 — Continuous GND copper pour passes directly under both encoder sense paths on every relevant layer

Zone `In1.GND` (`twin28xx.kicad_pcb` line 66621) is filled on **F.Cu, B.Cu, In1.Cu, In2.Cu** with a polygon (75.80, 96.55) → (75.78, 138.95) → (156.78, 138.95) → (157.78, 93.45) — i.e. the entire active region. The two `(keepout …)` blocks at lines 66599 and 82824 are KiCad *placement* rule areas, not copper exclusions (all five `allowed` flags). No copper keepout exists anywhere in the file.

Geometric verification (script `_review/datasheets/_check_zone.py`): the encoder centers (95.000, 120.0275) and (135.000, 120.0275) lie inside `In1.GND` filled-polygons on **F.Cu, In1.Cu, and B.Cu**. (On In2.Cu the GND polygon does not cover those points because In2.Cu is dominated by VCC zones — but VCC copper is just as opaque to magnetic flux.) Thus continuous copper sits on every metal layer between the magnet and the encoder die.

The MT6701 datasheet (Rev 1.5 / 1.8) does **not specify** copper-clearance requirements under the sensor. However: any conductor in the magnetic-flux path will (a) attenuate static field and (b) generate eddy currents under the rotating diametric field. Standard practice for axial Hall encoders is to remove copper from a circular region under the package on every layer; **this practice is not codified in the MT6701 datasheet**, so the recommendation here is engineering judgement, not a datasheet rule. The empirical risk is nonetheless real and additive to B1's gap problem.

**Fix**: after relocating to B.Cu (B1), add a circular `(zone … keep_out)` rule-area centered on each encoder die, on F.Cu / In1.Cu / In2.Cu / B.Cu, of diameter at least the magnet diameter (Dmag = 6.0 mm typ per §5) plus margin — 6–8 mm typical.
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

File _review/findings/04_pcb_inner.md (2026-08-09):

# 04 - PCB Inner Copper Layers (In1.Cu, In2.Cu) Review (v2, primary-source verified)

Board: 76.95 x 36.93 mm, 4-layer, 1.6167 mm thick (`twin28xx.kicad_pcb` line 6, `(thickness 1.61668)`). No impedance control specified.

## Stackup (verified, `twin28xx.kicad_pcb` lines 28-98)

| Layer | Material | Thickness | er | tan d |
|---|---|---|---|---|
| F.Cu | copper (line 43-46) | 0.035 mm  | - | - |
| dielectric 1 | prepreg Nan Ya NP-155F 7628 (line 47-54) | 0.2104 mm | 4.40  | 0.02  |
| In1.Cu | copper (line 55-58) | 0.0152 mm | - | - |
| dielectric 2 | core Nan Ya NP-155F Core (line 59-66)  | 1.065 mm  | 4.43  | 0.02  |
| In2.Cu | copper (line 67-70) | 0.0152 mm | - | - |
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

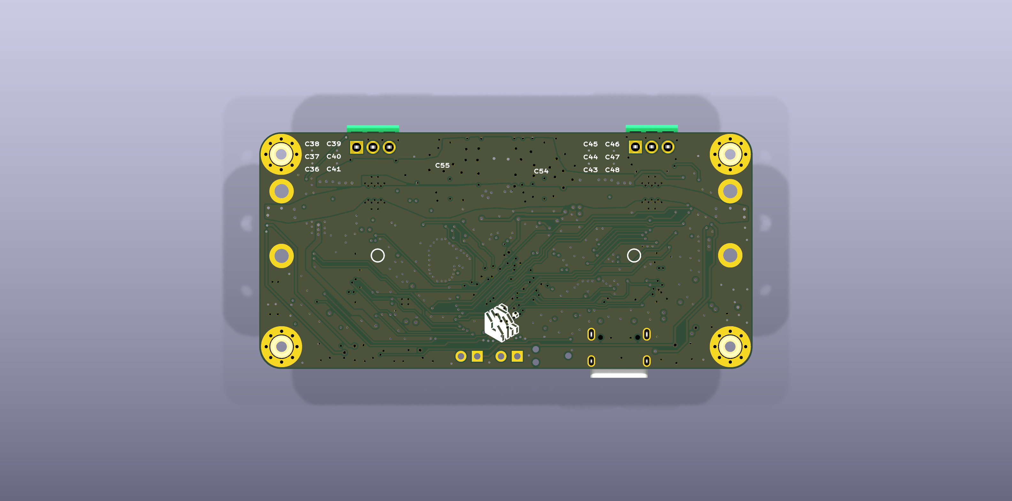
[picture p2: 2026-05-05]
review/renders/bottom_3d.png

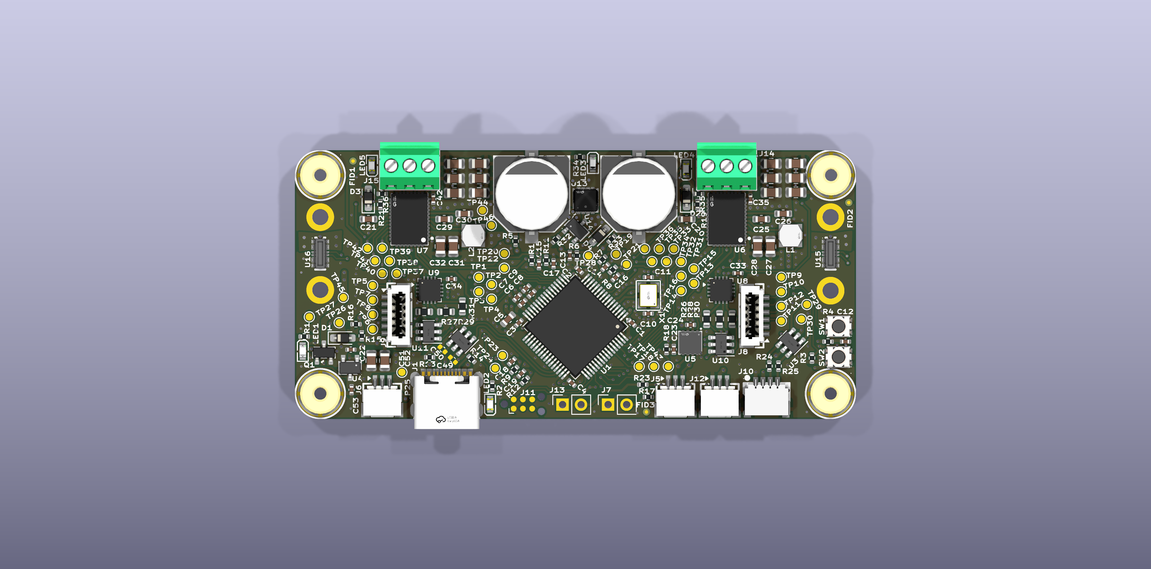
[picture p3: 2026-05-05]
review/renders/top_3d.png

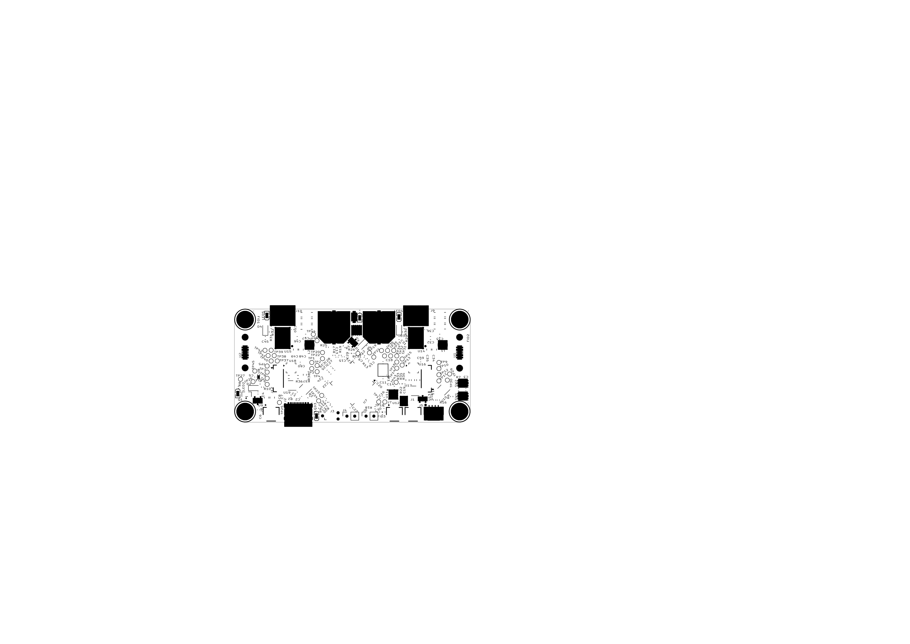
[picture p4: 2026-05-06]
_review/exports/layers_png/F.Silkscreen.png

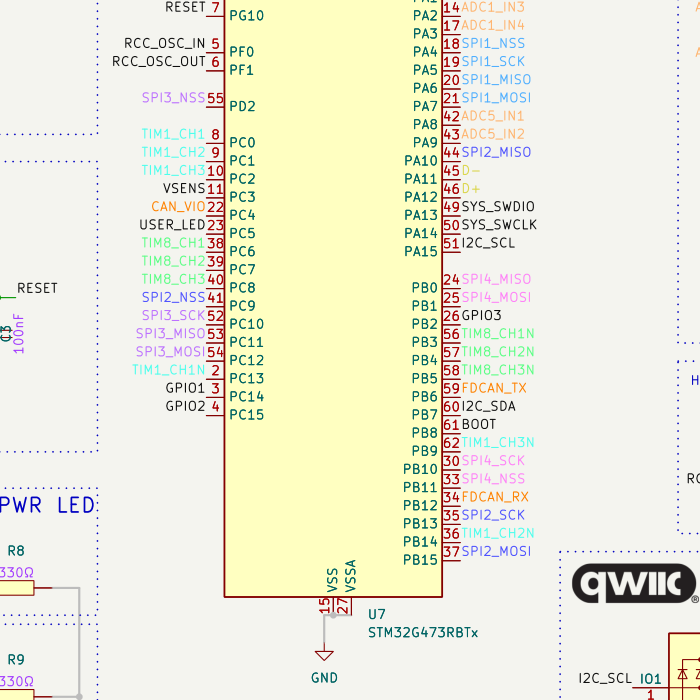
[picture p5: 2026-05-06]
_review/s1_boot_rst.png

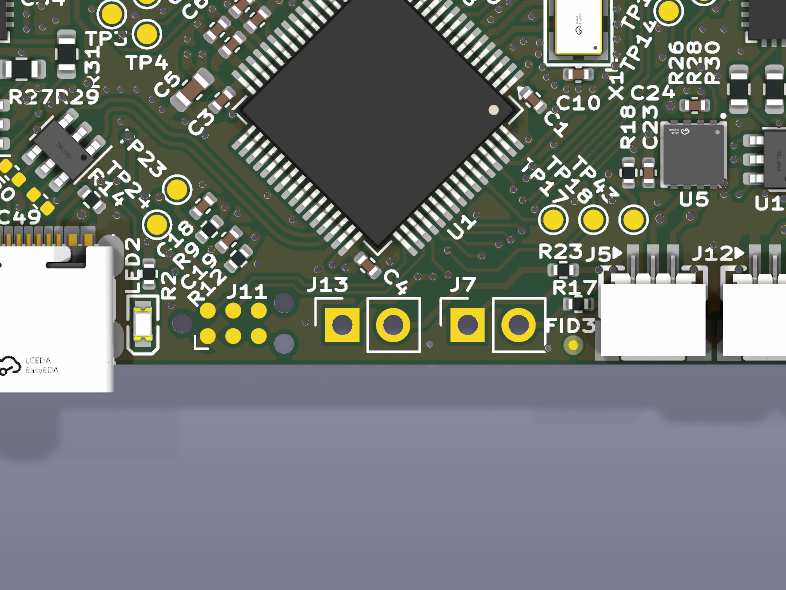
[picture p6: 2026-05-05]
review/crops/top_r1c1.png

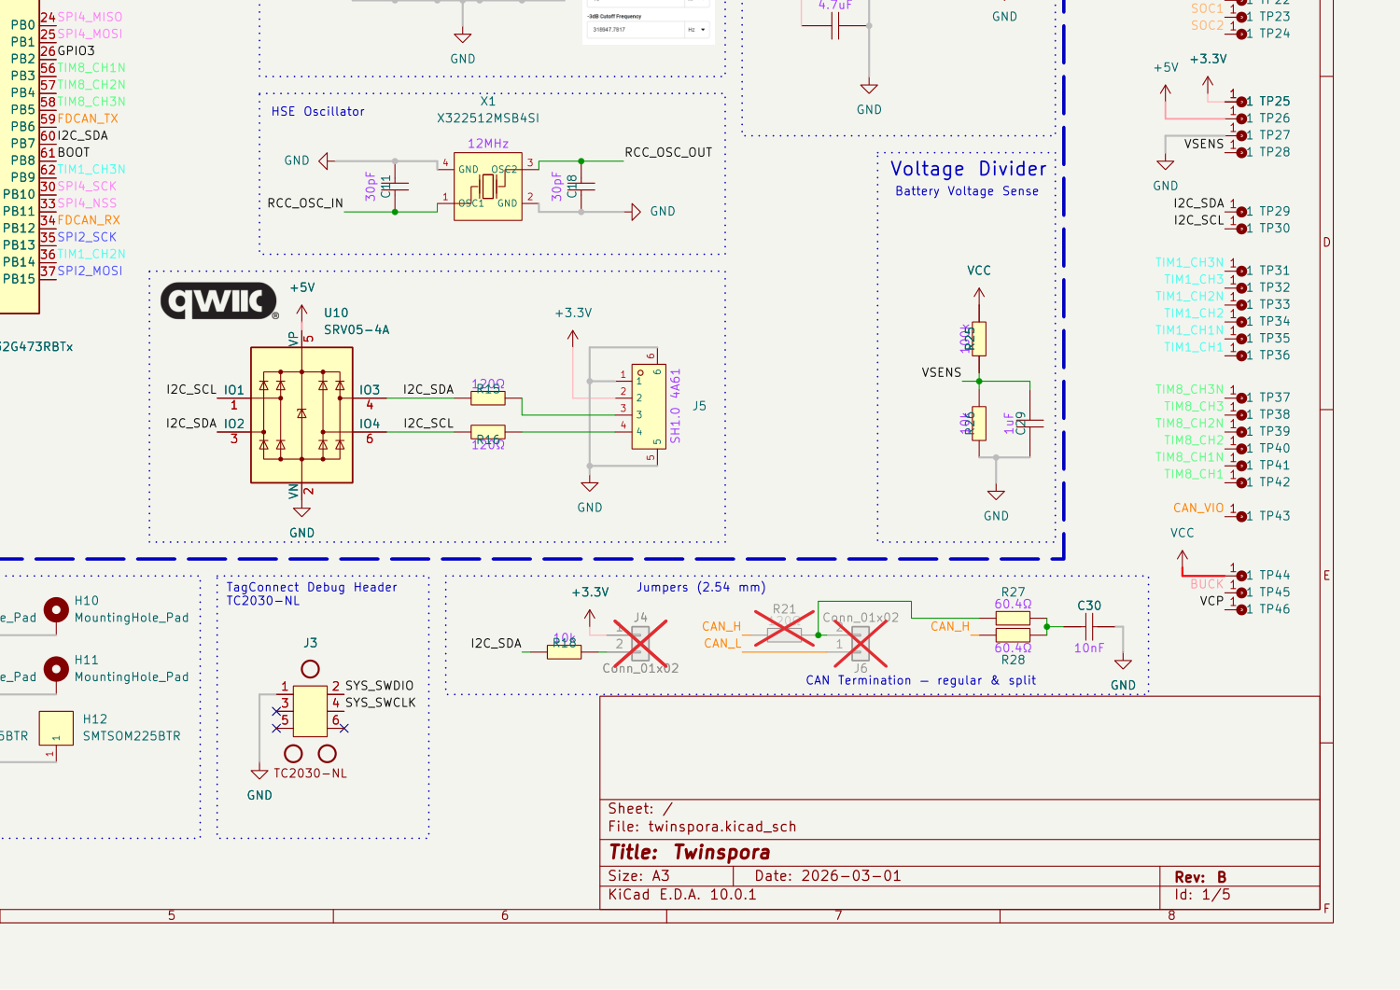
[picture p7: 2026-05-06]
_review/sheet1_q4.png

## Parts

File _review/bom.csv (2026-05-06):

Reference | Value | Footprint | Manufacturer | MPN | Description
C1,C2 | 0402CG470J500NT | Capacitor_SMD:C_0402_1005Metric |  |  | 47pF ±5% 50V Ceramic Capacitor C0G 0402
C3,C4,C6,C16,C19-C23,C25,C27,C36,C50,C59,C60 | CL05B104KB54PNC | Capacitor_SMD:C_0402_1005Metric |  |  | 100nF ±10% 50V Ceramic Capacitor X7R 0402
C5,C26,C28,C29 | CL05A105KA5NQNC | Capacitor_SMD:C_0402_1005Metric |  |  | 1uF ±10% 25V Ceramic Capacitor X5R 0402
C7,C8,C34,C35,C37-C42,C48,C49,C51-C56 | GRM21BR61H106KE43L | Capacitor_SMD:C_0805_2012Metric |  |  | 10uF ±10% 50V Ceramic Capacitor X5R 0805
C9,C10,C12,C13,C15,C17,C30 | CL05B103KB5NNNC | Capacitor_SMD:C_0402_1005Metric |  |  | 10nF ±10% 50V Ceramic Capacitor X7R 0402
C11,C18 | 0402CG300J500NT | Capacitor_SMD:C_0402_1005Metric |  |  | 30pF ±5% 50V Ceramic Capacitor C0G 0402
C14,C24 | CL10A475KO8NNNC | Capacitor_SMD:C_0603_1608Metric |  |  | CAP CER 4.7uF 16V X5R 0603
C31,C33,C45,C47 | CL10A105KB8NNNC | Capacitor_SMD:C_0603_1608Metric |  |  | 1uF ±10% 50V Ceramic Capacitor X5R 0603
C32,C46 | CL10B473KB8NNNC | Capacitor_SMD:C_0603_1608Metric |  |  | 47nF ±10% 50V Ceramic Capacitor X7R 0603
C43,C57 | EEEFT1H331GP | Capacitor_SMD_UWRL:CAP-SMD_BD10.0-L10.3-W10.3-LS11.0-R-RD
C44,C58 | 50PX330MEFC10X16 | Capacitor_THT_UWRL:CAP-TH_BD10.0-P5.00-D1.0-FD
D1,D2 | 1N4148WS_T4 | Diode_SMD:D_SOD-323_HandSoldering
D3,D4 | BZT52B5V1S_C19077434 | Diode_SMD:D_SOD-323_HandSoldering
H3,H6,H9,H12 | SMTSOM225BTR | Mechanical:SMD_BD5.6-D3.6
J1,J7,J8 | XY-SH1_0-3A61 | Connector_SH1.0:CONN-SMD_3P-P1.00_XYECONN_XY-SH1.0-3A61
J2 | TYPE-C-31-M-12 | Connector_USB:USB-C_SMD-TYPE-C-31-M-12_1
J4,J6 | Conn_01x02 |  |  |  | Generic connector, single row, 01x02, script generated (kicad-library-utils/schlib/autogen/connector/)
J5 | XY-SH1_0-4A61 | Connector_SH1.0:CONN-SMD_4P-P1.00-WT
J9,J10 | Conn_01x03 |  |  |  | Generic connector, single row, 01x03, script generated (kicad-library-utils/schlib/autogen/connector/)
J11,J12 | XY-SH1_0-6A51 | Connector_SH1.0:CONN-SMD_6P-P1.00_XY-SH1.0-6A51
L1,L2 | PRS3015-470MT | Inductor:IND-SMD_L3.0-W3.0_PRS3015
LED1,LED2 | KT-0603W | LED:LED0603-R-RD_WHITE
LED3-LED5 | KT-0603R | LED:LED0603-RD
Q1 | AO3401A | Package_TO_SOT_SMD:SOT-23 |  |  | -4.0A Id, -30V Vds, P-Channel MOSFET, SOT-23
R1,R4,R7,R11,R18,R22,R26 | 0402WGF1002TCE | Resistor_SMD:R_0402_1005Metric |  |  | 10kΩ ±1% 62.5mW 0402 Thick Film Resistor
R2,R3,R5,R6 | 0402WGF5101TCE | Resistor_SMD:R_0402_1005Metric |  |  | 5.1kΩ ±1% 62.5mW 0402 Thick Film Resistor
R8-R10,R30,R32 | 0402WGF3300TCE | Resistor_SMD:R_0402_1005Metric |  |  | RES 330Ω ±1% 62.5mW 0402
R12-R14,R17,R19,R20 | 0402WGF499JTCE | Resistor_SMD:R_0402_1005Metric |  |  | 49.9Ω ±1% 62.5mW 0402 Thick Film Resistor
R15,R16,R21 | 0402WGF1200TCE | Resistor_SMD:R_0402_1005Metric |  |  | 120Ω ±1% 62.5mW 0402 Thick Film Resistor
R23,R24,R33-R38 | 0603WAF0000T5E | Resistor_SMD:R_0603_1608Metric |  |  | 0Ω ±1% 100mW 0603 Thick Film Resistor
R25,R29,R31 | 0402WGF1003TCE | Resistor_SMD:R_0402_1005Metric |  |  | 100kΩ ±1% 62.5mW 0402 Thick Film Resistor
R27,R28 | 0402WGF604JTCE | Resistor_SMD:R_0402_1005Metric |  |  | RES 60.4Ω ±1% 62.5mW 0402
SW1,SW2 | SKSGPAE010 | Switch_UWRL:SW-SMD_SKSGAAE010
U1,U2 | BK22C07-4DP/2-0_4V(800) | Connector_HRS_BK22:CONN-SMD_4P-P0.40_BAM04-08073-0414
U3 | FMMT620TA | Transistor_BJT_UWRL:SOT-23-3_L2.9-W1.6-P1.90-LS2.8-BR
U4 | WSD4066DN | Transistor_FET_UWRL:DFN-8_L3.2-W3.1-P0.65-LS3.4-BL-EP
U5 | SMF30CA_C19077519 | Diode_UWRL:SOD-123FL_L2.7-W1.8-LS3.8-BI
U6,U10,U17,U19 | SRV05-4A | Diode:SOT-23-6 |  |  | ESD Protection Diodes with Low Clamping Voltage, SOT-23-6
U7 | STM32G473RBTx | Package_QFP:LQFP-64_10x10mm_P0.5mm |  |  | STMicroelectronics Arm Cortex-M4 MCU, 128KB flash, 128KB RAM, 170 MHz, 1.71-3.6V, 52 GPIO, LQFP64
U8 | H5VN10B | Diode_UWRL:DFN1006-2L-BI
U9 | XC6206P332MR | Regulator_Linear:SOT-23-3_L2.9-W1.6-P1.90-LS2.8-BR
U11 | CA-IF1044VD-Q1 | Interface_CAN_LIN:DFN-8_L3.0-W3.0-P0.65-BL-EP2.45
U12 | ACT1210D-101-2P-TL00 | CMC_UWRL:FILTER-SMD_4P-L3.2-W2.5-BL_ACT1210D-101-2P-TL00
U13 | PESD2CAN | Diode_UWRL:SOT-23-3_L2.9-W1.3-P1.90-LS2.4-BR
U14,U15 | DRV8316CRRGFR | Motor_Driver:VQFN-40_L7.0-W5.0-P0.50-BL-EP5.7
U16,U18 | MT6701QT | Package_DFN_QFN:QFN-16-1EP_3x3mm_P0.5mm_EP1.7x1.7mm |  |  | Hall Based Angle Position Encoder Sensor, I2C, SSI, ABZ & UVW interfaces, 3.3..5V supply, QFN-16
X1 | X322512MSB4SI | Oscillator:X322512MSB4SI |  |  | Crystal 12MHz ±10ppm 20pF SMD3225-4P

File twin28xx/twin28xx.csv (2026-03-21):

Reference | Qty | Value | DNP | Exclude from BOM | Exclude from Board | Footprint | Datasheet | Description
C1,C2,C3,C4,C8,C12,C20,C22,C23,C24,C25,C29,C33,C34 | 14 | CL05B104KB54PNC |  |  |  | Basic_Capacitors_Resistors:C0402 | https://item.szlcsc.com/15869.html | 100nF ±10% 50V Ceramic Capacitor X7R 0402
C5 | 1 | CL10A475KO8NNNC |  |  |  | Basic_Capacitors_Resistors:C0603 | https://item.szlcsc.com/362304.html | CAP CER 4.7uF 16V X5R 0603
C6,C14,C15,C16,C17,C18,C19 | 7 | CL05B103KB5NNNC |  |  |  | Basic_Capacitors_Resistors:C0402 | https://item.szlcsc.com/15869.html | 10nF ±10% 50V Ceramic Capacitor X7R 0402
C7,C9,C13,C26,C28,C30,C32 | 7 | CL05A105KA5NQNC |  |  |  | Basic_Capacitors_Resistors:C0402 | https://item.szlcsc.com/15869.html | 1uF ±10% 25V Ceramic Capacitor X5R 0402
C10,C11 | 2 | 0402CG200J500NT |  |  |  | Basic_Capacitors_Resistors:C0402 | https://item.szlcsc.com/15869.html | 20pF ±5% 50V Ceramic Capacitor C0G 0402
C21,C27,C31 | 3 | CL10A226MQ8NRNC |  |  |  | Basic_Capacitors_Resistors:C0603 | https://item.szlcsc.com/362304.html | 22uF ±20% 6.3V Ceramic Capacitor X5R 0603
D1 | 1 | 1N4148WS |  |  |  | Diode_SMD:D_SOD-323 | https://www.vishay.com/docs/85751/1n4148ws.pdf | 75V 0.15A Fast switching Diode, SOD-323
D2,D3 | 2 | BZT52B5V1S |  |  |  | Diode:SOD-323_L1.7-W1.3-LS2.6-RD | https://atta.szlcsc.com/upload/public/pdf/source/20200225/C485496_BB753C4664B20481CFEA6C9542536A94.pdf
J1 | 1 | TYPE-C-31-M-12 |  |  |  | Connector_USB:USB-C_SMD-TYPE-C-31-M-12_1 | https://item.szlcsc.com/datasheet/TYPE-C-31-M-12/177331.html
J2 | 1 | XT30U-M |  |  |  | Connector_AMASS:AMASS_XT30PW-M_1x02_P2.50mm_Horizontal | https://atta.szlcsc.com/upload/public/pdf/source/20170606/1496716542582.pdf
J3 | 1 | XT60PW-M | DNP |  |  | Connector_AMASS:AMASS_XT60PW-M_1x02_P7.20mm_Horizontal | https://atta.szlcsc.com/upload/public/pdf/source/20180125/C98732_15168617837851301983.pdf
J4,J5 | 2 | XY-XH2_54-2A21 |  |  |  | Connector_XH2.54:HDR-TH_2P-P2.50_XY-XH2.54-2A21 | https://atta.szlcsc.com/upload/public/pdf/source/20231124/D66390E8C06C0EE50596E66A88591188.pdf
J6 | 1 | Conn_01x02 |  |  |  |  |  | Generic connector, single row, 01x02, script generated (kicad-library-utils/schlib/autogen/connector/)
J7 | 1 | XY-XH2_54-2A21 | DNP |  |  | Connector_XH2.54:HDR-TH_2P-P2.50_XY-XH2.54-2A21 | https://atta.szlcsc.com/upload/public/pdf/source/20231124/D66390E8C06C0EE50596E66A88591188.pdf
J8,J9 | 2 | XY-SH1_0-6A51 | DNP |  |  | Connector_SH1.0:CONN-SMD_6P-P1.00_XY-SH1.0-6A51 | https://atta.szlcsc.com/upload/public/pdf/source/20231128/C6B60C64F4338683BC8BC065CCF39725.pdf
J10 | 1 | XY-SH1_0-4A61 |  |  |  | Connector_SH1.0:CONN-SMD_4P-P1.00-WT | https://cn.bing.com/search?q=datasheet1.0WT-2P
J11 | 1 | XY-XH2_54-3A11 | DNP |  |  | Connector_XH2.54:HDR-TH_3P-P2.50-V-F-2 | https://atta.szlcsc.com/upload/public/pdf/source/20230919/F0DE05943B9FA56F5E26D8736A3970EA.pdf
L1,L2 | 2 | PRS3015-470MT |  |  |  | Inductor:IND-SMD_L3.0-W3.0_PRS3015 | https://item.szlcsc.com/97352.html
LED1 | 1 | KT-0603W |  |  |  | LED:LED0603-R-RD_WHITE | https://atta.szlcsc.com/upload/public/pdf/source/20180604/C192669_B0D472CB769BD043C4F2A33F1E72AA62.pdf
LED2 | 1 | KT-0603R |  |  |  | LED:LED0603-RD | https://item.szlcsc.com/347874.html
Q1 | 1 | AO3401A |  |  |  | Package_TO_SOT_SMD:SOT-23 | http://www.aosmd.com/pdfs/datasheet/AO3401A.pdf | -4.0A Id, -30V Vds, P-Channel MOSFET, SOT-23
R1,R3,R13,R14,R20,R22 | 6 | 0402WGF5101TCE |  |  |  | Basic_Capacitors_Resistors:R0402 | https://item.szlcsc.com/323315.html | 5.1kΩ ±1% 62.5mW 0402 Thick Film Resistor
R2,R15 | 2 | 0402WGF3300TCE |  |  |  | Basic_Capacitors_Resistors:R0402 | https://item.szlcsc.com/323315.html | RES 330Ω ±1% 62.5mW 0402
R4,R6,R16,R18 | 4 | 0402WGF1002TCE |  |  |  | Basic_Capacitors_Resistors:R0402 | https://item.szlcsc.com/323315.html | 10kΩ ±1% 62.5mW 0402 Thick Film Resistor
R5,R19,R21 | 3 | 0402WGF1003TCE |  |  |  | Basic_Capacitors_Resistors:R0402 | https://item.szlcsc.com/323315.html | 100kΩ ±1% 62.5mW 0402 Thick Film Resistor
R7,R8,R9,R10,R11,R12 | 6 | 0402WGF499JTCE |  |  |  | Basic_Capacitors_Resistors:R0402 | https://item.szlcsc.com/323315.html | 49.9Ω ±1% 62.5mW 0402 Thick Film Resistor
R17 | 1 | 0402WGF1200TCE |  |  |  | Basic_Capacitors_Resistors:R0402 | https://item.szlcsc.com/323315.html | 120Ω ±1% 62.5mW 0402 Thick Film Resistor
SW2,SW3 | 2 | TS1187A26020 |  |  |  | Switch:SW-SMD_4P-L5.2-W5.2-1 | https://atta.szlcsc.com/upload/public/pdf/source/20240320/DB82FD9773CCA5064BFEA54B1A9AE2A7.pdf
U1 | 1 | STM32G473RBTx |  |  |  | Package_QFP:LQFP-64_10x10mm_P0.5mm | https://www.st.com/resource/en/datasheet/stm32g473rb.pdf | STMicroelectronics Arm Cortex-M4 MCU, 128KB flash, 128KB RAM, 170 MHz, 1.71-3.6V, 52 GPIO, LQFP64
U4 | 1 | XC6206P332MR |  |  |  | Regulator_Linear:SOT-23-3_L2.9-W1.6-P1.90-LS2.8-BR | https://item.szlcsc.com/14454.html
U5 | 1 | CA-IF1044VD-Q1 |  |  |  | Interface_CAN_LIN:DFN-8_L3.0-W3.0-P0.65-BL-EP2.45 | https://img.jlc.com/pdf/applyPasteComponent/2023-03-02/5356285A/ddb042fd7bd043febc14583bb55c8ec3/2901.pdf
U6,U7 | 2 | DRV8316CRRGFR |  |  |  | Motor_Driver:VQFN-40_L7.0-W5.0-P0.50-BL-EP5.7 | https://www.ti.com/lit/ds/symlink/mct8316z-q1.pdf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
U8,U9 | 2 | MT6701QT |  |  |  | Package_DFN_QFN:QFN-16-1EP_3x3mm_P0.5mm_EP1.7x1.7mm | https://www.magntek.com.cn/upload/MT6701_Rev.1.5.pdf | Hall Based Angle Position Encoder Sensor, I2C, SSI, ABZ & UVW interfaces, 3.3..5V supply, QFN-16
X1 | 1 | X322512MSB4SI |  |  |  | Oscillator:X322512MSB4SI | https://item.szlcsc.com/15866.html | Crystal 12MHz ±10ppm 20pF SMD3225-4P

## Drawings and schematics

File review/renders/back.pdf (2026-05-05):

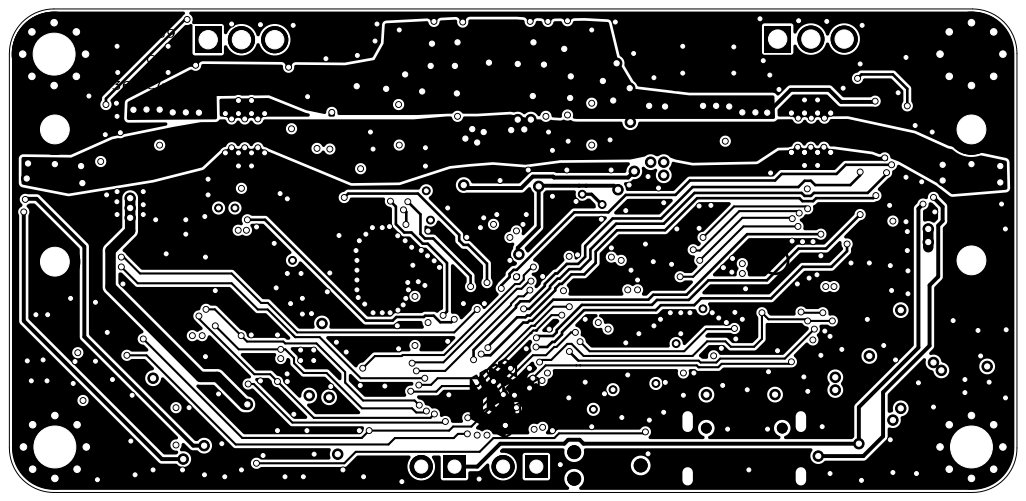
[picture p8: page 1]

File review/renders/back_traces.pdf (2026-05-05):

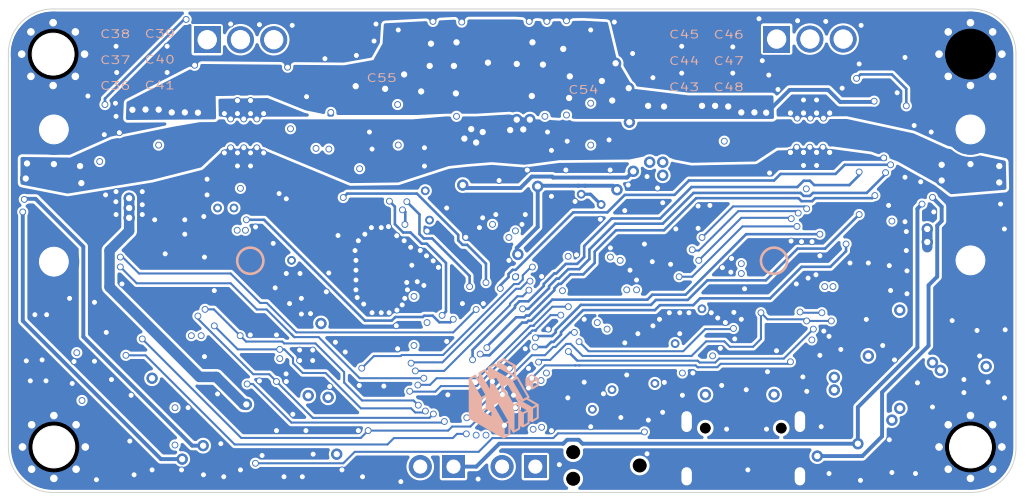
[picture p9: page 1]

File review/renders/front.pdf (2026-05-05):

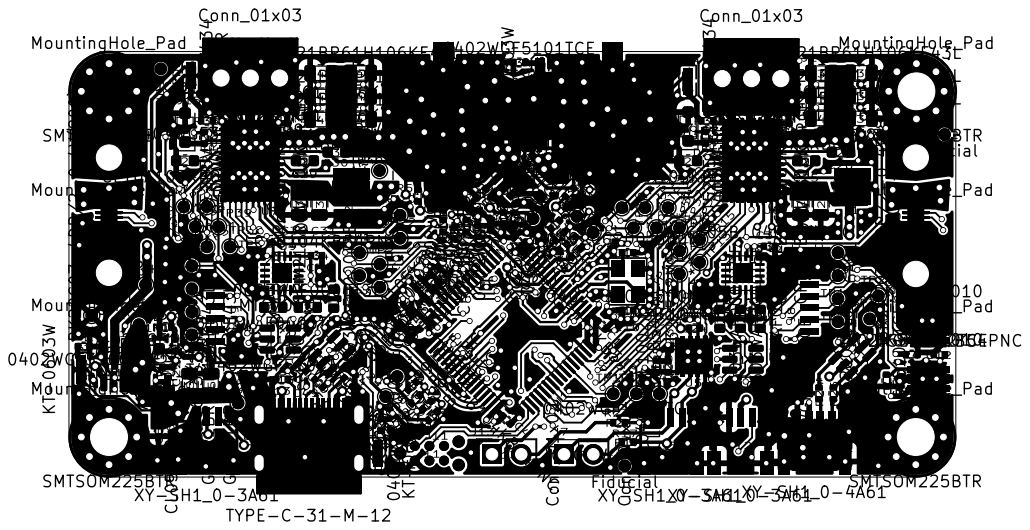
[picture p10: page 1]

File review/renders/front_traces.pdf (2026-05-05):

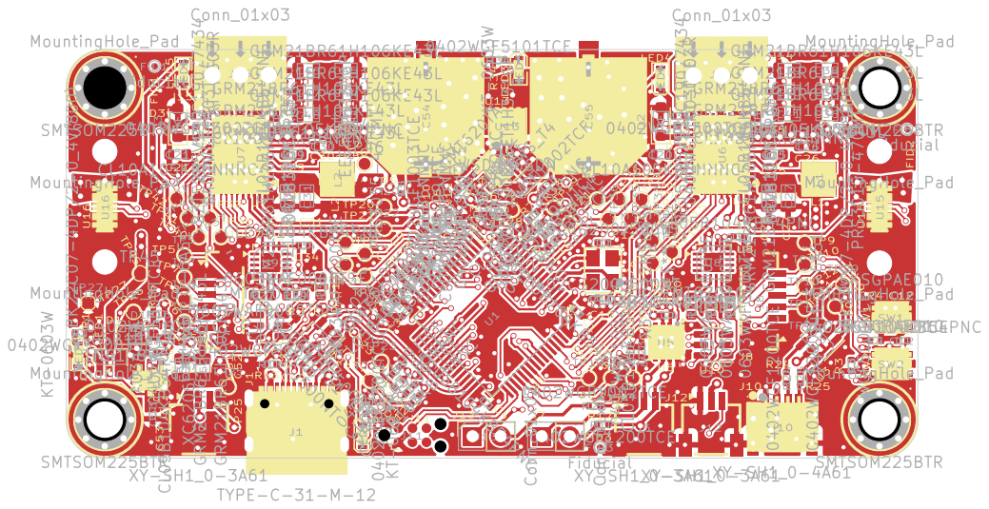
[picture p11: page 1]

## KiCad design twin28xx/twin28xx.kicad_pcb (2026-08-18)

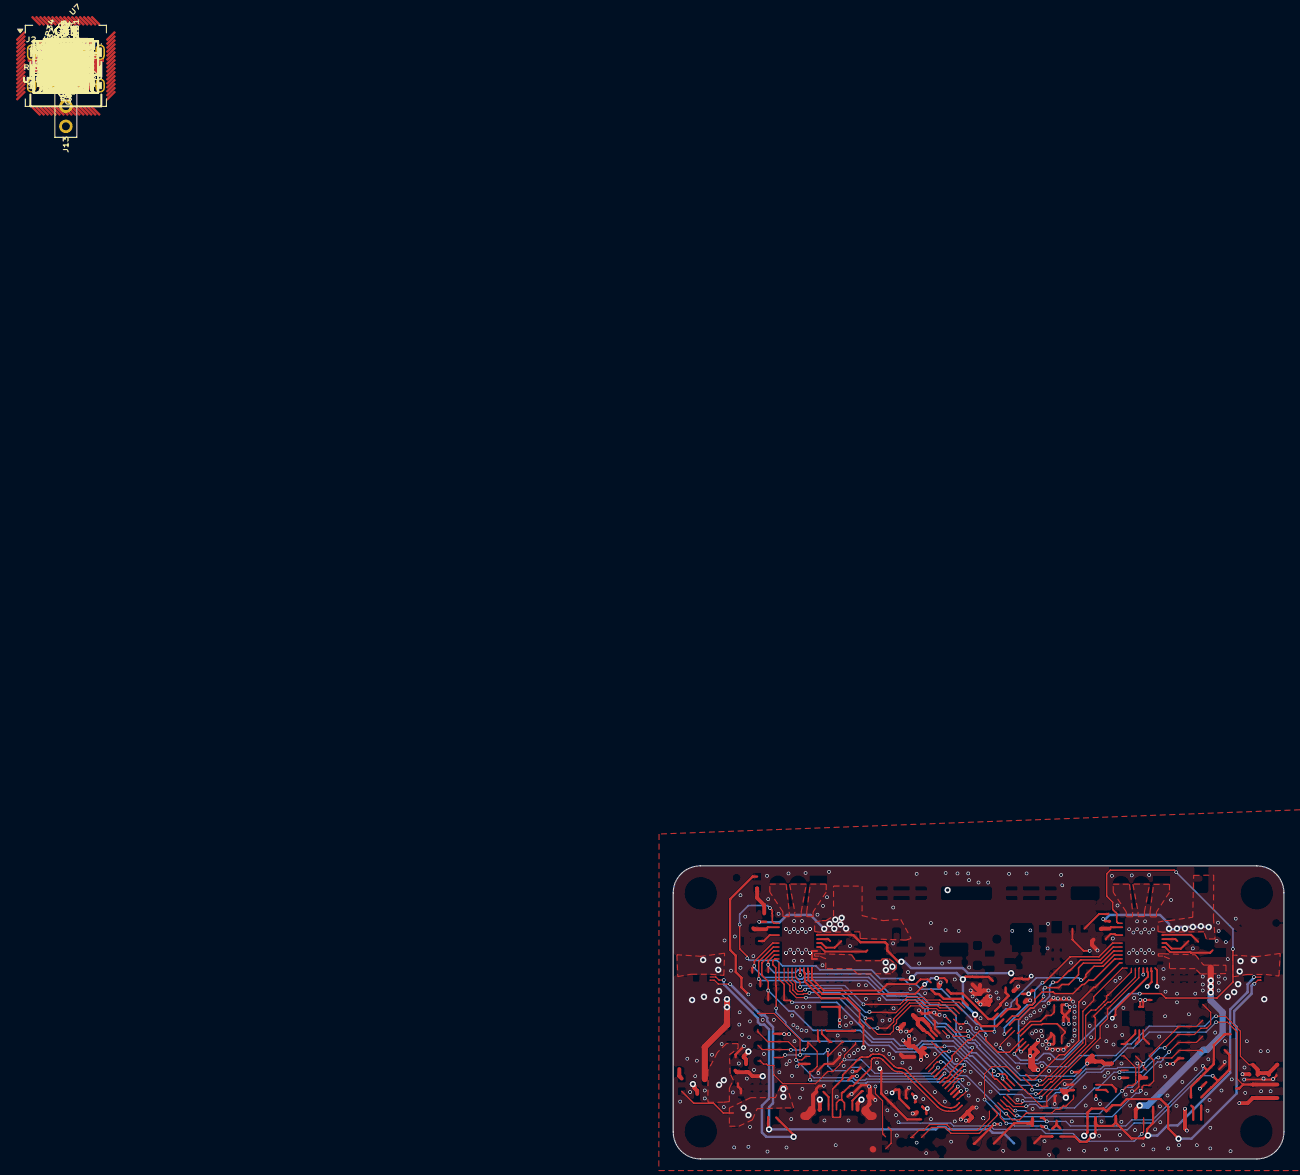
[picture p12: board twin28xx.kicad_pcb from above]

Board: 4 copper layers, 76.9 x 36.9 mm, 201 parts (0 on the bottom side), 111 nets.

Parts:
C1, C2: 0402CG470J500NT; C_0402_1005Metric
C3, C4, C6, C16, C19, C20, C21, C22, C23, C25, C27, C36, C50, C59, C60: CL05B104KB54PNC; C_0402_1005Metric
C5, C26, C28, C29: CL05A105KA5NQNC; C_0402_1005Metric
C7, C8, C34, C35, C37, C48, C49, C51: GRM21BR61H106KE43L; C_0805_2012Metric
C9, C10, C12, C13, C15, C17, C30: CL05B103KB5NNNC; C_0402_1005Metric
C11, C18: 0402CG300J500NT; C_0402_1005Metric
C14, C24: CL10A475KO8NNNC; C_0603_1608Metric
C31, C33, C45, C47: CL10A105KB8NNNC; C_0603_1608Metric
C32, C46: CL10B473KB8NNNC; C_0603_1608Metric
C38, C39, C40, C41, C42, C43: VHXC0581V101MVCG; CP_Elec_6.3x5.8
D1, D2: 1N4148WS_T4; D_SOD-323_HandSoldering
D3, D4: BZT52B5V1S_C19077434; D_SOD-323_HandSoldering
FID1, FID2, FID3: Fiducial; Fiducial_0.5mm_Mask1mm
H1, H4, H7, H10: MountingHole_Pad; MountingHole_3.2mm_M3_Pad_Via
H2, H5, H8, H11: MountingHole_Pad; MountingHole_2.2mm_M2_DIN965_Pad
H3, H6, H9, H12: SMTSOM225BTR; SMD_BD5.6-D3.6
J1, J7, J8: XY-SH1_0-3A61; CONN-SMD_3P-P1.00_XYECONN_XY-SH1.0-3A61
J2: TYPE-C-31-M-12; USB-C_SMD-TYPE-C-31-M-12_1
J3: Tag-Connect_TC2030-IDC-NL_2x03_P1.27mm_Vertical
J4: DB125-2_54-2P-GN__mirror; CONN-TH_DB125-2.54-2P-GN__mirror
J5: XY-SH1_0-4A61; CONN-SMD_4P-P1.00_XYECONN_XY-SH1.0-4A61
J6: DB125-2_54-2P-GN; CONN-TH_DB125-2.54-2P-GN
J9, J10: Conn_01x03; CONN-TH_DB125-2.54-3P-GN
J11, J12: XY-SH1_0-6A51; CONN-SMD_6P-P1.00_XY-SH1.0-6A51
J13: Conn_01x04; PinHeader_1x04_P2.54mm_Vertical
L1, L2: PRS3015-470MT; IND-SMD_L3.0-W3.0_PRS3015
L3: GZ1608D601TF; L_0603_1608Metric
LED1, LED2: KT-0603W; LED0603-R-RD_WHITE
LED3, LED4, LED5: KT-0603R; LED0603-RD
Q1: AO3401A; SOT-23
R1, R4, R7, R11, R22, R26: 0402WGF1002TCE; R_0402_1005Metric
R2, R3, R5, R6, R18, R40: 0402WGF5101TCE; R_0402_1005Metric
R8, R9, R10, R30, R39: 0402WGF3300TCE; R_0402_1005Metric
R12, R13, R14, R17, R19, R20: 0402WGF499JTCE; R_0402_1005Metric
R15, R16, R21: 0402WGF1200TCE; R_0402_1005Metric
R23, R24, R31, R32, R33, R34, R36, R37, R38: 0603WAF0000T5E; R_0603_1608Metric
R25, R29, R35: 0402WGF1003TCE; R_0402_1005Metric
R27, R28: 0402WGF604JTCE; R_0402_1005Metric
SW1, SW2: SKSGPAE010; SW-SMD_SKSGAAE010
TP1, TP2, TP3, TP4, TP5, TP6, TP7, TP8, TP9, TP10, TP11, TP12, TP13, TP14, TP15, TP16, TP17, TP18, TP19, TP20, TP21, TP22, TP23, TP24, TP25, TP26, TP27, TP28, TP29, TP30, TP31, TP32, TP33, TP34, TP35, TP36, TP37, TP38, TP39, TP40, TP41, TP42, TP43, TP44, TP45, TP46: TestPoint_Pad_D1.0mm
U1, U2: BK22C07-4DP/2-0_4V(800); CONN-SMD_4P-P0.40_BAM04-08073-0414
U3: FMMT620TA; SOT-23-3_L2.9-W1.6-P1.90-LS2.8-BR
U4: WSD4066DN; DFN-8_L3.2-W3.1-P0.65-LS3.4-BL-EP
U5: SMF30A_C19077518; SOD-123FL_L2.7-W1.8-LS3.8
U6, U10, U17, U19: SRV05-4A; SOT-23-6
U7: STM32G473RBTx; LQFP-64_10x10mm_P0.5mm
U8: TPD1E10B06DPYR; DFN1006-2L-BI
U9: XC6206P332MR; SOT-23-3_L2.9-W1.6-P1.90-LS2.8-BR
U11: CA-IF1044VD-Q1; DFN-8_L3.0-W3.0-P0.65-BL-EP2.45
U12: ACT1210D-101-2P-TL00; FILTER-SMD_4P-L3.2-W2.5-BL_ACT1210D-101-2P-TL00
U13: PESD2CAN; SOT-23-3_L2.9-W1.3-P1.90-LS2.4-BR
U14, U15: DRV8316CRRGFR; VQFN-40_L7.0-W5.0-P0.50-BL-EP5.7
U16, U18: MT6701QT; QFN-16-1EP_3x3mm_P0.5mm_EP1.7x1.7mm
X1: X322512MSB4SI

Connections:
+3.3V: C6.2, C7.1, C8.1, C20.1, C21.1, C22.1, C23.1, C24.1, C59.2, C60.2, J5.2, J11.2, J12.2, J13.4, L3.2, LED2.1 (A), LED4.2 (A), LED5.2 (A), R7.2, R34.2, SW1.1, SW1.3, TP25.1 (1_1), U7.1 (VBAT), U7.16 (VDD), U7.32 (VDD), U7.48 (VDD), U7.64 (VDD), U9.3 (Vout), U10.5 (VP), U14.37 (VREF/ILIM), U15.37 (VREF/ILIM), U16.13 (VDD), U16.14 (MODE), U17.5 (VP), U18.13 (VDD), U18.14 (MODE), U19.5 (VP)
+5V: C4.2, C5.2, C14.2, C16.2, D2.1 (K), Q1.2 (S), TP26.1 (1_1), U8.2, U9.2 (Vin), U11.3 (VCC)
+BATT: D1.1 (K), J4.2, J6.2, U1.5, U1.6, U1.9, U1.10, U2.5, U2.6, U2.9, U2.10, U4.1 (S1), U4.3 (S2)
/5V_BKOUT: C34.1, C35.1, J1.2, L1.1, U14.3 (FB_BK)
/ADC1_IN3: C9.2, R12.1, U7.14 (PA2)
/ADC1_IN4: C13.2, R17.1, U7.17 (PA3)
/ADC2_IN1: C10.2, R13.1, U7.12 (PA0)
/ADC2_IN2: C15.2, R19.1, U7.13 (PA1)
/ADC5_IN1: C12.2, R14.1, U7.42 (PA8)
/ADC5_IN2: C17.2, R20.1, U7.43 (PA9)
/BOOT: R6.2, SW1.2, SW1.4, U7.61 (PB8)
/BUCK: C48.1, C49.1, L2.1, Q1.3 (D), TP45.1 (1_1), U15.3 (FB_BK)
/CAN_H: J7.3, J8.3, R21.2, R23.2, R28.2, U1.4, U2.4, U12.4, U13.1
/CAN_L: J7.2, J8.2, J13.2, R24.2, U1.3, U2.3, U12.3, U13.2
/CAN_VIO: C19.2, R22.2, TP43.1 (1_1), U7.22 (PC4), U11.5 (VIO/NC)
/CC1: J2.A5 (CC1), R2.1
/CC2: J2.B5 (CC2), R3.1
/D+: C2.2, J2.A6 (DP1), J2.B6 (DP2), U6.1 (IO1), U6.6 (IO4), U7.46 (PA12)
/D-: C1.2, J2.A7 (DN1), J2.B7 (DN2), U6.3 (IO2), U6.4 (IO3), U7.45 (PA11)
/FDCAN_RX: TP18.1 (1_1), U7.34 (PB12), U11.4 (RXD)
/FDCAN_TX: TP17.1 (1_1), U7.59 (PB6), U11.1 (TXD)
/GPIO1: R30.2, U7.3 (PC14), U14.22 (nFAULT)
/GPIO2: R39.2, U7.4 (PC15), U15.22 (nFAULT)
/GPIO3: J1.3, U7.26 (PB2)
/I2C_SCL: R16.2, R40.1, TP30.1 (1_1), U7.51 (PA15), U10.1 (IO1), U10.6 (IO4)
/I2C_SDA: R15.1, R18.1, TP29.1 (1_1), U7.60 (PB7), U10.3 (IO2), U10.4 (IO3)
/PHA1: J9.1, U14.13 (OUTA), U14.14 (OUTA)
/PHA2: J10.1, U15.13 (OUTA), U15.14 (OUTA)
/PHB1: J9.2, U14.16 (OUTB), U14.17 (OUTB)
/PHB2: J10.2, U15.16 (OUTB), U15.17 (OUTB)
/PHC1: J9.3, U14.19 (OUTC), U14.20 (OUTC)
/PHC2: J10.3, U15.19 (OUTC), U15.20 (OUTC)
/RCC_OSC_IN: C11.1, U7.5 (PF0), X1.1 (OSC1)
/RCC_OSC_OUT: C18.2, U7.6 (PF1), X1.3 (OSC2)
/RESET: C3.2, R7.1, SW2.1, SW2.3, U7.7 (PG10)
/SOA1: R12.2, TP19.1 (1_1), U14.40 (SOA)
/SOA2: R17.2, TP20.1 (1_1), U15.40 (SOA)
/SOB1: R13.2, TP21.1 (1_1), U14.39 (SOB)
/SOB2: R19.2, TP22.1 (1_1), U15.39 (SOB)
/SOC1: R14.2, TP23.1 (1_1), U14.38 (SOC)
/SOC2: R20.2, TP24.1 (1_1), U15.38 (SOC)
/SPI1_MISO: TP4.1 (1_1), U7.20 (PA6), U15.33 (SDO)
/SPI1_MOSI: TP3.1 (1_1), U7.21 (PA7), U15.34 (SDI)
/SPI1_NSS: TP1.1 (1_1), U7.18 (PA4), U15.36 (nSCS)
/SPI1_SCK: TP2.1 (1_1), U7.19 (PA5), U15.35 (SCLK)
/SPI2_MISO: J12.4, R36.1, TP8.1 (1_1), U7.44 (PA10), U19.6 (IO4)
/SPI2_MOSI: J12.3, TP7.1 (1_1), U7.37 (PB15), U19.4 (IO3)
/SPI2_NSS: J12.5, R37.1, TP5.1 (1_1), U7.41 (PC9), U19.3 (IO2)
/SPI2_SCK: J12.6, R38.1, TP6.1 (1_1), U7.35 (PB13), U19.1 (IO1)
/SPI3_MISO: J11.4, R33.1, TP12.1 (1_1), U7.53 (PC11), U17.6 (IO4)
/SPI3_MOSI: J11.3, TP11.1 (1_1), U7.54 (PC12), U17.4 (IO3)
/SPI3_NSS: J11.5, R32.1, TP9.1 (1_1), U7.55 (PD2), U17.3 (IO2)
/SPI3_SCK: J11.6, R31.1, TP10.1 (1_1), U7.52 (PC10), U17.1 (IO1)
/SPI4_MISO: TP16.1 (1_1), U7.24 (PB0), U14.33 (SDO)
/SPI4_MOSI: TP15.1 (1_1), U7.25 (PB1), U14.34 (SDI)
/SPI4_NSS: TP13.1 (1_1), U7.33 (PB11), U14.36 (nSCS)
/SPI4_SCK: TP14.1 (1_1), U7.30 (PB10), U14.35 (SCLK)
/SYS_SWCLK: J3.4, U7.50 (PA14)
/SYS_SWDIO: J3.2, U7.49 (PA13)
/TIM1_CH1: TP36.1 (1_1), U7.8 (PC0), U14.27 (INHA)
/TIM1_CH1N: TP35.1 (1_1), U7.2 (PC13), U14.28 (INLA)
/TIM1_CH2: TP34.1 (1_1), U7.9 (PC1), U14.29 (INHB)
/TIM1_CH2N: TP33.1 (1_1), U7.36 (PB14), U14.30 (INLB)
/TIM1_CH3: TP32.1 (1_1), U7.10 (PC2), U14.31 (INHC)
/TIM1_CH3N: TP31.1 (1_1), U7.62 (PB9), U14.32 (INLC)
/TIM8_CH1: TP42.1 (1_1), U7.38 (PC6), U15.27 (INHA)
/TIM8_CH1N: TP41.1 (1_1), U7.56 (PB3), U15.28 (INLA)
/TIM8_CH2: TP40.1 (1_1), U7.39 (PC7), U15.29 (INHB)
/TIM8_CH2N: TP39.1 (1_1), U7.57 (PB4), U15.30 (INLB)
/TIM8_CH3: TP38.1 (1_1), U7.40 (PC8), U15.31 (INHC)
/TIM8_CH3N: TP37.1 (1_1), U7.58 (PB5), U15.32 (INLC)
/USER_LED: LED3.2 (A), U7.23 (PC5)
/VCP: C47.2, R4.2, TP46.1 (1_1), U15.8 (CP)
/VDDA_DECOUPLE: C25.1, C26.1, C27.1, C28.1, L3.1, R34.1, U7.28 (VREF+), U7.29 (VDDA)
/VSENS: C29.2, R25.1, R26.2, TP28.1 (1_1), U7.11 (PC3)
/motor_driver/VCP: C33.2, U14.8 (CP)
GND: C1.1, C2.1, C3.1, C4.1, C5.1, C6.1, C7.2, C8.2, C9.1, C10.1, C11.2, C12.1, C13.1, C14.1, C15.1, C16.1, C17.1, C18.1, C19.1, C20.2, C21.2, C22.2, C23.2, C24.2, C25.2, C26.2, C27.2, C28.2, C29.1, C30.1, C31.1, C34.2, C35.2, C36.1, C37.1, C38.2, C39.2, C40.2, C41.2, C42.2, C43.2, C45.1, C48.2, C49.2, C50.1, C51.1, C59.1, C60.1, D3.2 (A), D4.2 (A), H1.1 (1_1), H2.1 (1_1), H3.1 (1_1), H4.1 (1_1), H5.1 (1_1), H6.1 (1_1), H7.1 (1_1), H8.1 (1_1), H9.1 (1_1), H10.1 (1_1), H11.1 (1_1), H12.1 (1_1), J1.1, J1.4, J1.5, J2.1 (EH), J2.2 (EH), J2.3 (EH), J2.4 (EH), J2.A1B12 (GND), J2.B1A12 (GND), J3.1, J4.1, J5.1, J5.5, J5.6, J6.1, J7.1, J7.4, J7.5, J8.1, J8.4, J8.5, J11.1, J11.7, J11.8, J12.1, J12.7, J12.8, R1.1, R2.2, R3.2, R5.2, R6.1, R8.2, R9.2, R11.1, R22.1, R26.1, SW1.5, SW1.6, SW2.2, SW2.4, SW2.5, SW2.6, TP27.1 (1_1), U1.7, U1.8, U1.11, U1.12, U2.7, U2.8, U2.11, U2.12, U5.2 (A), U6.2 (VN), U7.15 (VSS), U7.27 (VSSA), U7.31 (VSS), U7.47 (VSS), U7.63 (VSS), U8.1, U9.1 (GND), U10.2 (VN), U11.2 (GND), U11.8 (STB), U11.9 (EP), U13.3, U14.2 (AGND), U14.4 (GND_BK), U14.12 (PGND), U14.15 (PGND), U14.18 (PGND), U14.26 (AGND), U14.41 (PAD), U15.2 (AGND), U15.4 (GND_BK), U15.12 (PGND), U15.15 (PGND), U15.18 (PGND), U15.26 (AGND), U15.41 (PAD), U16.16 (GND), U16.17 (GND), U17.2 (VN), U18.16 (GND), U18.17 (GND), U19.2 (VN), X1.2 (GND), X1.4 (GND)
unnamed: C30.2, R27.2, R28.1
unnamed: D1.2 (A), U3.2 (E)
unnamed: D3.1 (K), R29.1, U14.23 (nSLEEP)
unnamed: D4.1 (K), R35.1, U15.23 (nSLEEP)
unnamed: J5.3, R15.2
unnamed: J5.4, R16.1
unnamed: J13.1, R21.1, R27.1
unnamed: J13.3, R18.2, R40.2
unnamed: LED1.2 (K), R5.1
unnamed: LED2.2 (K), R8.1
unnamed: LED3.1 (K), R9.1
unnamed: LED4.1 (K), R30.1
unnamed: LED5.1 (K), R39.1
unnamed: Q1.1 (G), R10.1, R11.2
unnamed: R1.2, U3.1 (B)
unnamed: R4.1, U3.3 (C), U4.2 (G1), U4.4 (G2)
unnamed: R23.1, U11.7 (CANH), U12.1
unnamed: R24.1, U11.6 (CANL), U12.2
unnamed: C31.2, U14.25 (AVDD)
unnamed: C32.2, U14.7 (CPH)
unnamed: C32.1, U14.6 (CPL)
unnamed: L1.2, U14.5 (SW_BK)
unnamed: C45.2, U15.25 (AVDD)
unnamed: C46.2, U15.7 (CPH)
unnamed: C46.1, U15.6 (CPL)
unnamed: L2.2, U15.5 (SW_BK)
unnamed: R33.2, U16.6 (A)
unnamed: R32.2, U16.7 (B)
unnamed: R31.2, U16.8 (Z)
unnamed: R36.2, U18.6 (A)
unnamed: R37.2, U18.7 (B)
unnamed: R38.2, U18.8 (Z)
VBUS: D2.2 (A), J2.A4B9 (VBUS), J2.B4A9 (VBUS), R10.2, U6.5 (VP)
VCC: C33.1, C36.2, C37.2, C38.1, C39.1, C40.1, C41.1, C42.1, C43.1, C47.1, C50.2, C51.2, LED1.1 (A), R25.2, R29.2, R35.2, TP44.1 (1_1), U4.5 (D2), U4.6 (D2), U4.7 (D1), U4.8 (D1), U4.9 (D1), U4.10 (D2), U5.1 (C), U14.9 (VM), U14.10 (VM), U14.11 (VM), U15.9 (VM), U15.10 (VM), U15.11 (VM)

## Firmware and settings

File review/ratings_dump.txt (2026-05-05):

======================================================================
DRV8316.pdf  (95 pages)
======================================================================

--- p1 ---
  ? 1.5-?A at VVM = 24-V, TA = 25?C
  1/2-H bridges with 40-V absolute maximum capability
  4.5V to 35V (40V abs max)

--- p2 ---
  7.1 Absolute Maximum Ratings........................................ 6
  7.3 Recommended Operating Conditions.........................6

--- p6 ---
  7.1 Absolute Maximum Ratings
  Power supply pin voltage (VM) ?0.3 40 V
  Power supply voltage ramp (VM) 4 V/?s
  Charge pump voltage (CPH, CP) ?0.3 VM + 6 V
  Charge pump negative switching pin voltage (CPL) ?0.3 VM + 0.3 V
  Switching node pin voltage (SW_BK) ?0.3 VM + 0.3 V
  Output pin voltage (OUTA, OUTB, OUTC) ?1 VM + 1 V
  Junction temperature, TJ ?40 150 ?C
  (1) Operation outside the Absolute Maximum Ratings may cause permanent device damage. Absolute Maximum Ratings do not imply
  functional operation of the device at these or any other conditions beyond those listed under Recommended Operating Conditions.
  If used outside the Recommended Operating Conditions but within the Absolute Maximum Ratings, the device may not be fully
  7.3 Recommended Operating Conditions
  VVM Power supply voltage VVM 4.5 24 35 V
  TA Operating ambient temperature ?40 125 ?C
  TJ Operating Junction temperature ?40 150 ?C

--- p7 ---
  R?JA Junction-to-ambient thermal resistance 25.7 ?C/W
  R?JC(top) Junction-to-case (top) thermal resistance 15.2 ?C/W
  R?JB Junction-to-board thermal resistance 7.3 ?C/W
  ?JT Junction-to-top characterization parameter 0.2 ?C/W
  ?JB Junction-to-board characterization parameter 7.2 ?C/W
  R?JC(bot) Junction-to-case (bottom) thermal resistance 2.0 ?C/W
  TJ = ?40?C to +150?C, VVM = 4.5 to 35 V (unless otherwise noted). Typical limits apply for TA = 25?C, VVM = 24 V
  VVM > 6 V, nSLEEP = 0, TA = 25 ?C 1.5 2.5 ?A
  'OFF', BUCK_DIS = 1; 4 10 mA
  VVM > 6 V, nSLEEP = 1, INHx = INLx =
  0, SPI = 'OFF', TA = 25 ?C, BUCK_DIS =
  VVM > 6 V, nSLEEP = 1, INHx = INLx
  'OFF', IBK = 0, BUCK_DIS = 0; 6 10 mA
  VVM > 6 V, nSLEEP = 1, fPWM = 25 kHz,
  TA = 25 ?C, BUCK_DIS = 1 10 13 mA
  VVM > 6 V, nSLEEP = 1, fPWM = 200 kHz,
  TA = 25 ?C, BUCK_DIS = 1 18 21 mA
  nSLEEP =1, fPWM = 25 kHz, BUCK_DIS
  BUCK_DIS = 1 17 25 mA
  VVM > 6 V, nSLEEP = 1, fPWM =
  25 kHz, TA = 25 ?C, BUCK_DIS =
  VVM > 6 V, nSLEEP = 1, fPWM =
  200 kHz, TA = 25 ?C, BUCK_DIS =
  nSLEEP =1, fPWM = 25 kHz, BUCK_DIS
  = 0; BUCK_PS_DIS = 0 12 17 mA

--- p8 ---
  TJ = ?40?C to +150?C, VVM = 4.5 to 35 V (unless otherwise noted). Typical limits apply for TA = 25?C, VVM = 24 V
  VVM > 6 V, 0 mA ? IBK ? 200 mA,
  BUCK_SEL = 00b 3.1 3.3 3.5 V
  VVM > 6 V, 0 mA ? IBK ? 200 mA,
  BUCK_SEL = 01b 4.6 5.0 5.4 V
  VVM > 6 V, 0 mA ? IBK ? 200 mA,
  BUCK_SEL = 10b 3.7 4.0 4.3 V
  VVM > 6.7 V, 0 mA ? IBK ? 200 mA,
  BUCK_SEL = 11b 5.2 5.7 6.2 V
  VVM < 6.0 V (BUCK_SEL = 00b, 01b,
  10b) or VVM < 6.0 V (BUCK_SEL = 11b),
  VVM  > 6 V, 0 mA ? IBK ? 50 mA,
  BUCK_SEL = 00b 3.1 3.3 3.5 V
  VVM > 6 V, 0 mA ? IBK ? 50 mA,
  BUCK_SEL = 01b 4.6 5.0 5.4 V
  VVM  > 6 V, 0 mA ? IBK ? 50 mA,
  BUCK_SEL = 10b 3.7 4.0 4.3 V
  VVM  > 6.7 V, 0 mA ? IBK ? 50 mA,
  BUCK_SEL = 11b 5.2 5.7 6.2 V
  VVM < 6.0 V (BUCK_SEL = 00b, 01b,
  10b) or VVM < 6.0 V (BUCK_SEL = 11b),
  VVM  > 6 V, 0 mA ? IBK ? 40 mA,
  BUCK_SEL = 00b 3.1 3.3 3.5 V
  VVM > 6 V, 0 mA ? IBK ? 40 mA,
  BUCK_SEL = 01b 4.6 5.0 5.4 V

--- p9 ---
  TJ = ?40?C to +150?C, VVM = 4.5 to 35 V (unless otherwise noted). Typical limits apply for TA = 25?C, VVM = 24 V
  VVM > 6 V, 0 mA ? IBK ? 50 mA,
  VVM > 6 V, 0 mA ? IBK ? 50
  VVM > 6 V, 0 mA ? IBK ? 50
  VVM > 6.7 V, 0 mA ? IBK ? 50 mA,
  VVM < 6.0 V, 0 mA ? IBK ? 50 mA
  VVM > 6 V, 0 mA ? IBK ? 40 mA,
  VVM > 6 V, 0 mA ? IBK ? 40
  VVM > 6 V, 0 mA ? IBK ? 40
  VVM > 6.7 V, 0 mA ? IBK ? 40 mA,
  VVM  < 6.0 V, 0 mA ? IBK ? 40 mA
  VVM  > 6 V, 0 mA ? IBK ? 200 mA, Buck
  VVM  > 6 V, 0 mA ? IBK ? 50 mA, Buck
  VVM  > 6 V, 0 mA ? IBK ? 50 mA, Buck
  BUCK_PS_DIS = 1b 200 mA
  22 ?F, BUCK_PS_DIS = 1b 50 mA
  22 ?F, BUCK_PS_DIS = 1b 40 mA

--- p10 ---
  TJ = ?40?C to +150?C, VVM = 4.5 to 35 V (unless otherwise noted). Typical limits apply for TA = 25?C, VVM = 24 V
  VBK rising, BUCK_SEL = 00b 2.7 2.8 2.9 V
  VBK falling, BUCK_SEL = 00b 2.5 2.6 2.7 V
  VBK rising, BUCK_SEL = 01b 4.2 4.4 4.55 V
  VBK falling, BUCK_SEL = 01b 4.0 4.2 4.35 V
  VBK rising, BUCK_SEL = 10b 2.7 2.8 2.9 V
  VBK falling, BUCK_SEL = 10b 2.5 2.6 2.7 V
  VBK rising, BUCK_SEL = 11b 4.2 4.4 4.55 V
  VBK falling, BUCK_SEL = 11b 4 4.2 4.35 V
  BUCK_CL = 0b 360 600 900 mA
  BUCK_CL = 1b 80 150 250 mA
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

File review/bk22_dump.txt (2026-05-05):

======================================================================
BK22_catalog.pdf (10 pages)
======================================================================

--- p1 ---
BK22 Series
0.4mm Pitch, 0.7mm Stacking Height, 15A Rated Current, 
Power/Signal Hybrid FPC-to-Board Connector
Feb. 2025
Product Page
https://www.hirose.com/en/product/series/BK22
Apr.1.2026 Copyright 2026 HIROSE ELECTRIC CO., LTD. All Rights Reserved.

--- p2 ---
2
BK22 Series/0.4mm Pitch, 0.7mm Stacking Height, 15A Rated Current, Power/Signal Hybrid FPC-to-Board Connector
Features
1.    Space-saving Design with 15A 
Rated Current
The power contact supports 15A per position and the 
signal contact supports 0.3A per position for high power 
supply capability.
Additionally, the BK22 has a space-saving design that 
minimizes connector size. 
2.  Robust Design
The fully armored design guide and center portion 
prevent housing damage due to misalignment when 
mating. 
3.  High Contact Reliability
Multi-point contact design with 6-point power contacts 
and 2-point signal contacts for stable connection.
Increase the Rated Current from 10A to 15A 
While Achieving Space Reduction 
(14.3% Decrease in PCB Mounting Space)
Multi-point Contact 
PCB Mounting Space : 14.17mm
2
0.4mm Pitch 
2 Power Pos. / 6 Signal Pos. 
Rated Current : 
Power Contact 10A
0.4mm Pitch 
2 Power Pos. / 6 Signal Pos. 
Rated Current : 
Power Contact 15A
Conventional Product
BK22 PCB Mounting Space : 12.40mm
2
<Receptacle>
Power Contact 
6-Point Contact
Signal Contact 
2-Point Contact
Fully Armored Design
<Conventional Products>
Exposed
Housing
 Housing is 
Covered by 
Metal
<BK22>
Guide
Center
No Metal Parts Only Partially Covered 
with Metal
Apr.1.2026 Copyright 2026 HIROSE ELECTRIC CO., LTD. All Rights Reserved.

--- p3 ---
3
BK22 Series/0.4mm Pitch, 0.7mm Stacking Height, 15A Rated Current, Power/Signal Hybrid FPC-to-Board Connector
4.  Superior Mating Operability
5.  Halogen-Free
Wide self-alignment range with metal guides offers
enhanced mating operation. 
(0.47mm in pitch direction, 0.405mm in width direction)
Furthermore, a clear tactile click generated by the unique
locking contact design secures completed mating.
All materials and substances used to produce this product 
comply with Halogen-Free standards.
*  As defined by IEC 61249-2-21  
Br : 900ppm max., Cl : 900ppm max., Br+Cl : 1,500ppm max.
- Space-saving 
- High Current Capacity
- Compatible with USB Power Delivery
- Easy to Replace USB Connector 
- No Need for Main Board Height Alignment*
*   By using an FPC to connect the USB to the PCB,  
the USB can be placed anywhere within the design of 
the end  product.
Devices that require low-profile, compact design such as smartphones, wearable terminals and tablet PCs.
Applications
? Battery Connection ? USB Connection
Effectively uses dead space to 
expand self-alignment range 
when mating
Metal Guide Ribs
Built-in
Battery
Housing
Housing
USB
PCB
Apr.1.2026 Copyright 2026 HIROSE ELECTRIC CO., LTD. All Rights Reserved.
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

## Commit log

2026-02-23 chip add
    remaining components:
    C5447274 -- DRV8316CRRGFR
    C5155979 -- CA-IF1044VD-Q1
    C19077434 -- BZT52B5V1S
    C22459526 -- TS1187A26020
    C2875244 -- CJ15-160000810A20
    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
    [twinspora.kicad_sch]
2026-02-24 g473 labels
    [twinspora.kicad_sch]
2026-02-24 schematic and library work
    [twinspora.kicad_sch]
2026-02-25 finished schematic, added connectors
    [twinspora.kicad_sch]
2026-02-26 new adc lpf values
    [twinspora.kicad_pcb, twinspora.kicad_sch]
2026-03-21 fix library submodule reference
    Re-add the library submodule at twinspora/library — the previous
    submodule entry was dropped in bd3298c when the path was moved.
2026-03-21 added smt nut
    [motor_driver.kicad_sch, twinspora.csv, twinspora.kicad_pcb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]
2026-04-19 initial completion
    [magnetic_encoder.kicad_sch, motor_driver.kicad_sch, twinspora.kicad_pcb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]
2026-04-19 final designator edits
    [twinspora.kicad_pcb]
2026-04-19 sum stitching vias
    [twinspora.kicad_pcb]
2026-04-19 metric hole spacing
    [twinspora.kicad_pcb]
2026-04-22 apr 21 push
    [magnetic_encoder.kicad_sch, motor_driver.kicad_sch, twinspora.kicad_pcb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]
2026-04-24 CAN wrong pinout
    [twinspora.kicad_pcb, twinspora.kicad_sch]
2026-04-24 more stitching vias
    [twinspora.kicad_pcb]
2026-04-29 fix shit
    [magnetic_encoder.kicad_sch, motor_driver.kicad_sch, twinspora.kicad_pcb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]
2026-04-30 caps and leds and fault
    [twinspora.kicad_pcb, twinspora.kicad_sch]
2026-05-04 Bump library submodule to de9deff
    Brings the superproject pin in sync with library/main, which has been
    six commits ahead since blug -> fix shit. Restores the missing 3D bodies
    for the Panasonic 330uF cap, SKSGAAE010 button, FMMT620TA BJT, WSD4066DN
    MOSFET, and SOD-323 ESD diode (from 9f51b78 and e9cf902), and includes
    the new de9deff CAN transceiver inverted-normals fix.
2026-05-04 Bump library submodule to 276b60b for BK22 connector 3D model
    Adds the Hirose-supplied STP for BK22C07-4DP/2-0.4V(800) wired into the
    BAM04-08073-0414 footprint, replacing the missing 3D body that wasn't
    there before.
2026-05-04 b2b final
    [twinspora.kicad_pcb, twinspora.kicad_sch]
2026-05-05 MORE ESD
    [bk22_dump.txt, bom.csv, jlc_tvs_table.tsv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]
2026-05-06 split terminatino for can
    [bom.csv, magnetic_encoder.kicad_sch, motor_driver.kicad_sch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]
2026-05-07 rear silkscreen
    [motor_driver.kicad_sch, twinspora.kicad_pcb, twinspora.kicad_sch]
2026-05-07 new paths
    [twinspora.kicad_pcb]
2026-05-08 jlc time
    [twinspora.kicad_pcb]
2026-05-18 ferrite bead
    [twinspora-bom.csv, twinspora.kicad_pcb, twinspora.kicad_sch]
2026-05-18 fix silkscreen
    [magnetic_encoder.kicad_sch, motor_driver.kicad_sch, twinspora.kicad_pcb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]
2026-05-19 forgot the other i2c pullup
    [twinspora-bom-grouped.csv, twinspora.kicad_pcb, twinspora.kicad_sch]
2026-05-19 pcb edits for the above
    [twinspora.kicad_pcb]
2026-05-27 fix footprint lib_id refs, body-fill silk -> courtyard, SMT/M3 stack DRC rule
    - Rewrite PCB and schematic footprint lib_id references that used the pre-rename
    lib names (Capacitor_SMD_UWRL, Capacitor_THT_UWRL, Connector_DORABO,
    Connector_SH1.0, Diode, Inductor, LED, Motor_Driver, Basic_Capacitors_Resistors)
    to their current __C-suffixed names. Resolves the "Update PCB from Schematic"
    errors for the EEEFT cap, DRV8316, PRS3015, SOT-23-6 diodes, XY-SH1.0-6A51,
    and others.
    - Move filled silk polys on F.SilkS that cover footprint bodies to F.CrtYd
    (fill no) in PCB instances so they read as courtyard outlines, matching the
    library updates. Restore the body fill on the EEEFT cap, DOR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
    [magnetic_encoder.kicad_sch, motor_driver.kicad_sch, twinspora.kicad_pcb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]
2026-05-27 move library submodule to repo root and switch to ../library path convention
    Relocate library submodule from twinspora/library to top-level library/ so
    projects sit alongside it (matches giris's layout). Update fp-lib-table,
    sym-lib-table, and twinspora.kicad_pcb to reference ${KIPRJMOD}/../library/
    instead of ${KIPRJMOD}/library/. Library submodule pointer bumped to 7a4a7dd
    which uses the same path convention internally for 3D model references.
    [twinspora.kicad_pcb]
2026-08-09 rename project twinspora -> twin28xx
    Renames the KiCad project and every reference to it:
    - twinspora/ -> twin28xx/, and the project files within (.kicad_pro,
    .kicad_pcb, .kicad_sch, .kicad_prl, .kicad_dru, .csv)
    - twinspora-backups/ -> twin28xx-backups/ (archives keep their original
    KiCad-generated filenames)
    - refs/ netlists and BOM exports
    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
    [magnetic_encoder.kicad_sch, motor_driver.kicad_sch, twin28xx-bom-grouped.csv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]
2026-08-09 add power-delivery sim tooling + results; board edits; ignore KiCad locks/backups
    tools/power_sim: copper extractor (10.99 fork format), FDM current/thermal
    solver for +BATT/VCC/GND (feed right/left/both), ngspice bus-ripple and
    RC-damper studies. Results: board loop ~28-30 mOhm/driver single-fed vs
    ~19 mOhm dual-fed; copper safe to ~6A bus/driver at dT<=40K; ceramic-only
    bus resonates with battery-lead L at 15-22 kHz, so 330uF cans (or chip
    polymer replacements) must stay. Maps + ERC/DRC reports (0 errors) in
    tools/power_sim/results.
    [twin28xx.kicad_pcb]
2026-08-10 bump library submodule: Ymin VHXC hybrid cap + SMF30A TVS
    Points library at 545dccc (adds VHXC0581V101MVCG 100uF/35V hybrid and
    SMF30A TVS to the SMD symbol/footprint/3D libs).
2026-08-10 bump library submodule to main (66b0391)
    Consolidates the library onto main: project rename + Ymin VHXC 100uF/35V
    hybrid cap and SMF30A TVS.
2026-08-10 bump library submodule to f757289 (VHXC cap uses stock CP_Elec_6.3x5.8 footprint)
2026-08-18 swap bulk caps to VHXC hybrid, add second DRV8316 stage, relayout PCB
    - motor_driver: replace 5x GRM21BR61H106KE43L bulk caps with 3x
    VHXC0581V101MVCG hybrid caps; add U14 (DRV8316CRRGFR), L1
    (PRS3015-470MT), R29, and associated decoupling (C38-44, C52, C61-66)
    - PCB: relayout/reroute for the new parts
    - refs: add Ymin VHXC and Chuanghui SV101M datasheets
    - tools: add splitbank_sim.py power-delivery sim
    - analysis: track manifest.json (outputs stay ignored)
    [motor_driver.kicad_sch, twin28xx.kicad_pcb, twin28xx.kicad_sch]
